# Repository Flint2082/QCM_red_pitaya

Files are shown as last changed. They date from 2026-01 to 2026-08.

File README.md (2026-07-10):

# QCM_red_pitaya

FPGA code for a quartz crystal microbalance measurement system. 
Designed to run on the Red Pitaya FPGA.
made using the CASPER toolflow.

The theory behind this system is described in detail in the accompanying thesis (in Dutch):
[Scriptie_V1.0_Flint_Wardenaar.pdf](docs/Scriptie_V1.0_Flint_Wardenaar.pdf).

## Setup
Red Pitaya setup instructions are available in the [Red Pitaya documentation](src/README.md).

## Controlling the system
Once the control software is running on the Red Pitaya, the instrument can be
driven from a script over its HTTP + WebSocket API. See
[tools/README.md](tools/README.md) for a Python control guide
([`qcm_client.py`](tools/qcm_client.py)).

## Block diagram



## Algorithm 
The system measures the frequency shifts of two modes of a quartz crystal microbalance (QCM) sensor: a temperature sensitive mode and a mass sensitive mode. The frequency shifts are modeled as polynomial functions of temperature change and mass change, represented by the following equations:
```math
    \begin{aligned}
        \Delta f_T &= \lambda_{T_3} \cdot \Delta T^3 + \lambda_{T_2} \cdot \Delta T^2 + \lambda_{T_1} \cdot \Delta T + \lambda_{T_0} \cdot \Delta m \\
        \Delta f_M &= \lambda_{M_3} \cdot \Delta T^3 + \lambda_{M_2} \cdot \Delta T^2 + \lambda_{M_1} \cdot \Delta T + \lambda_{M_0} \cdot \Delta m 
    \end{aligned}
```
Where:
-  $` \Delta f_T `$ : Frequency shift of the temperature sensitive mode
-  $` \Delta f_M `$ : Frequency shift of the mass sensitive mode
-  $` \Delta T `$ : Temperature change
-  $` \Delta m `$ : Mass change
-  $` \lambda_{T_i} `$ : Temperature coefficients for the temperature sensitive mode
-  $` \lambda_{M_i} `$ : Temperature coefficients for the mass sensitive mode

To isolate the temperature change $\Delta T$, we eliminate the mass change $\Delta m$ from the equations:
```math
    (\lambda_{M_3} \cdot \lambda_{T_0} - \lambda_{T_3} \cdot \lambda_{M_0}) \cdot \Delta T^3 +
    (\lambda_{M_2} \cdot \lambda_{T_0} - \lambda_{T_2} \cdot \lambda_{M_0}) \cdot \Delta T^2 + \\
    (\lambda_{M_1} \cdot \lambda_{T_0} - \lambda_{T_1} \cdot \lambda_{M_0}) \cdot \Delta T +
    \lambda_{M_0} \cdot \Delta f_T - \lambda_{T_0} \cdot \Delta f_M = 0
```
Then once $\Delta T$ is determined, we can substitute it back into one of the original equations to find the mass change $\Delta m$:
```math
    \Delta m = \frac{\Delta f_M - (\lambda_{M_3} \cdot \Delta T^3 + \lambda_{M_2} \cdot \Delta T^2 + \lambda_{M_1} \cdot \Delta T)}{\lambda_{M_0}}    
```

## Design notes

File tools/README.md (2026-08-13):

# Controlling the QCM from Python

The QCM control software on the Red Pitaya exposes an HTTP + WebSocket API (the
same one the web UI uses). [`qcm_client.py`](qcm_client.py) is a thin Python
wrapper around that API, so you can drive the instrument from a script instead
of the browser: lock the PLLs, start/stop a measurement, change settings,
manage crystal profiles, and stream live data.

- **REST (HTTP)** — every action and setting. One method per endpoint.
- **WebSocket** (`/ws`) — live push stream of measurements and state changes.

---

## 1. Prerequisites

The control software must already be running on the Red Pitaya. If you set it
up as a service it is always running; otherwise start it over SSH:

```bash
ssh root@<red_pitaya_ip>
cd /root/QCM_red_pitaya
.venv/bin/python src/main.py          # add --no-opcua if there is no PLC
```

See [src/README.md](../src/README.md) for full setup and the systemd service
(`systemctl status qcm`).

The server listens on **port 8000** on all interfaces, so from your PC it is
reachable at `http://<red_pitaya_ip>:8000`. Quick sanity check:

```bash
curl http://<red_pitaya_ip>:8000/health        # -> {"status":"ok"}
```

## 2. Install the client dependencies (on your PC)

The client needs `requests`; live streaming additionally needs
`websocket-client`:

```bash
pip install requests websocket-client
```

Both are listed at the bottom of [requirements.txt](../requirements.txt).

## 3. Connect

`qcm_client.py` has no package install step — just import it from the `tools/`
folder (run your script from there, or add `tools/` to `sys.path`).

```python
from qcm_client import QCMClient

qcm = QCMClient("192.168.1.50")     # host of the Red Pitaya; port defaults to 8000
print(qcm.state())                  # "IDLE", "LOCKING", "RUNNING", ...
```

Every method maps to one endpoint and returns the parsed JSON response (most
write calls return `{"status": "ok"}`). HTTP errors raise
`requests.HTTPError`.

---

## 4. Typical workflow

The normal sequence is **get lock → start measurement → read data → stop**.

```python
import time
from qcm_client import QCMClient

qcm = QCMClient("192.168.1.50")

# 1. Pick the crystal whose calibration you want to use (lock frequencies +
#    polynomial coefficients come from this profile).
qcm.activate_crystal("AT_cut_6MHz")

# 2. Lock the two PLLs onto the crystal's resonances.
qcm.get_lock()
time.sleep(2)                       # give the loops time to settle
print("state:", qcm.state())        # -> "RUNNING" once locked

# 3. Start a measurement run. ambient_temp is required; the others have
#    sensible defaults (gold density, Z-ratio 1.0).
qcm.start_measurement(ambient_temp=23.0, mat_dens=19320.0, z_ratio=0.381)

# 4. Stream live measurements over the WebSocket.
for m in qcm.stream_measurements(limit=20):
    print(f"{m.calculated_thickness:8.3f} nm   {m.calculated_temp:6.2f} °C")

# 5. Stop and pull the server-side CSV log of the whole run.
qcm.stop_measurement()
qcm.download_latest_run("run.csv")
```

A ready-to-run version of this is [`qcm_demo.py`](qcm_demo.py):

```bash
python qcm_demo.py 192.168.1.50         # run from the tools/ folder
```

### Oscillator index convention

Settings that take an `oscillator_idx` use:

| index | mode |
|---|---|
| `1` | mass-sensitive mode |
| `2` | temperature-sensitive mode|

### System states

`qcm.state()` (and the pushed `StateEvent`) returns one of:
`IDLE`, `LOCKING`, `RUNNING`, `SWEEPING`, `CAP_ADJUST`.

---

## 5. Live streaming over the WebSocket

`stream_measurements()` yields one object per measurement, with attribute
access to the fields of `MeasurementData`:

| attribute | meaning |
|---|---|
| `timestamp` | epoch seconds |
| `freq_mass_mode` | mass-mode frequency (Hz) |
| `freq_temp_mode` | temp-mode frequency (Hz) |
| `compensated_freq` | temperature-compensated mass frequency |
| `uncompensated_thickness`| raw Sauerbrey thickness (nm) |
| `calculated_thickness` | temperature-compensated thickness (nm) |
| `calculated_temp` | crystal temperature from the model (°C)  |
| `amp_mass`, `amp_temp` | demodulated amplitudes |
| `phase_mass`, `phase_temp`| demodulated phases |
| `lock_mass`, `lock_temp` | per-mode lock status (bool) |
| `quality_mass`, `quality_temp` | phase-error σ over the lock window (rad), lower is better; `None` until the window fills |

Everything above the compensated values is also published on its own as
`TelemetryEvent`, which the worker emits whenever a run is *not* in progress —
those fields need no measurement reference, so they stay live while idle. During
a run they ride along on `MeasurementEvent` instead, never both.

`stream()` is the general form — pass `types=None` to receive every event, or a
tuple to filter. Event `type` values you can receive:
`StateEvent`, `MeasurementEvent`, `TelemetryEvent`, `LockStatusEvent`, `LockFailedEvent`,
`SweepPointEvent`, `SweepCompleteEvent`, `CapAdjustEvent`, `TargetReachedEvent`,
`StartFreqAutoUpdatedEvent`, `ErrorEvent`, `OpcStatusEvent`.

```python
# Watch state changes and lock events instead of measurements:
for ev in qcm.stream(types=("StateEvent", "LockStatusEvent", "LockFailedEvent")):
    print(ev.type, vars(ev))
```

The stream is read-only (the server only pushes), and `limit=None` streams
forever — break out of the loop or set a `limit` to stop.

---

## 6. API reference

All methods are on `QCMClient`. Frequencies are in Hz unless noted.

### Measurement control
| method | endpoint | notes |
|---|---|---|
| `get_lock()` | `POST /measurement/get_lock` | lock both PLLs at the active crystal's frequencies |
| `start_measurement(ambient_temp, mat_dens=19320.0, z_ratio=1.0)` | `POST /measurement/start` | `ambient_temp` required; `mat_dens` kg/m³ |
| `stop_measurement()` | `POST /measurement/stop` | |
| `state()` | `GET /state` | returns the state string |
| `set_target_thickness(value)` | `POST /settings/target_thickness` | nm; 0 = no target |
| `target()` | `GET /measurement/target` | current target + whether it has been reached |

### Target thickness

Set a target and the system raises a flag the moment the compensated thickness
reaches it: a `TargetReachedEvent` on the WebSocket, a popup in the web UI,
`GVL_QCM.READ.TargetReached` on the PLC, and `reached: true` from
`GET /measurement/target`. **The measurement is not stopped** — the flag says
the film is thick enough, and stopping is left to whoever is watching (the
operator's STOP button, or the PLC acting on the node).

The flag clears when the next run starts, or if the target is raised above the
current thickness. `0` disables the target entirely.

```python
qcm.set_target_thickness(250)          # nm
qcm.start_measurement(ambient_temp=23)
for ev in qcm.stream(types=("TargetReachedEvent",), limit=1):
    print(f"reached {ev.thickness:.1f} nm of {ev.target:.1f} nm")
qcm.stop_measurement()
```

### Oscillator / lock settings
| method | endpoint |
|---|---|
| `set_frequency(oscillator_idx, frequency)` | `POST /settings/frequency` |
| `set_integrator_gain(oscillator_idx, gain)` | `POST /settings/integrator_gain` |
| `set_lpf_freq(oscillator_idx, freq)` | `POST /settings/lpf_freq` (demod low-pass cutoff) |
| `set_inverted(oscillator_idx, inverted)` | `POST /settings/inverted` |
| `set_output_mode(mode)` | `POST /settings/output_mode` (DAC debug tap, int 0–11) |
| `set_lock_detect(phase_tolerance, phase_std)` | `POST /settings/lock_detect` (both rad: max mean phase error, max phase-error σ) |
| `set_auto_relock(enabled)` | `POST /settings/auto_relock` (auto re-acquire on lost lock, default on) |
| `set_lock_frequencies(mass, temp)` | `POST /settings/lock_frequencies` (transient, feeds `get_lock`) |
| `get_lock_frequencies()` | `GET /settings/lock_frequencies` |
| `set_coefficients(fM_0..fM_3, fT_0..fT_3)` | `POST /settings/coefficients` (compensation polynomial) |
| `settings()` | `GET /settings` (everything at once) |

### Crystal profiles
A crystal profile stores its lock frequencies, compensation coefficients and
sensor parameters. Activating one applies all of them.

| method | endpoint |
|---|---|
| `crystals()` | `GET /crystals` → `{"crystals": [...], "active": name}` |
| `crystal(name)` | `GET /crystals/{name}` |
| `create_crystal(name)` | `POST /crystals` (seeds from current settings) |
| `apply_crystal(name, **fields)` | `POST /crystals/{name}/apply` (save explicit values + apply now) |
| `activate_crystal(name)` | `POST /crystals/{name}/activate` |
| `save_current_to_crystal(name)` | `POST /crystals/{name}/save_current` |
| `delete_crystal(name)` | `DELETE /crystals/{name}` |

### Frequency sweep (characterise resonances)
| method | endpoint |
|---|---|
| `start_sweep(oscillator_idx, start_freq, stop_freq, step_size, settle_time)` | `POST /sweep/start` |
| `sweep_mode(oscillator_idx, settle_time=0.05)` | 500 kHz window at 1 kHz around the crystal's lock frequency |
| `abort_sweep()` | `POST /sweep/abort` |
| `sweeps()` | `GET /sweeps` — sweep CSVs on the Pitaya, newest first |
| `download_sweep(name, dest_path)` / `download_latest_sweep(dest_path)` | `GET /sweeps/{name}/download` |
| `delete_sweep(name)` | `DELETE /sweeps/{name}` |

While sweeping, the server pushes `SweepPointEvent` (`frequency`, `amplitude`,
`phase`) then a final `SweepCompleteEvent` whose `name` is the CSV the sweep was
recorded to (`None` if recording failed).

Every sweep is written to `data/sweeps/` on the Pitaya as it is taken, so it
survives a dropped WebSocket. `sweep_mode()` is the scripted form of the
**SWEEP fM** / **SWEEP fT** buttons in the UI: it centres a 500 kHz window,
stepped at 1 kHz, on the active crystal's mass or temp lock frequency. That is
a coarse locator — wide enough to find a resonance that has moved well away
from the stored frequency, but too coarse to resolve the peak's shape. Narrow
the range and re-run once you know roughly where it sits.

```python
qcm.sweep_mode(1)                                  # sweep around fM
for _ in qcm.stream(types=("SweepCompleteEvent",), limit=1):
    pass                                           # wait for it to finish
qcm.download_latest_sweep("sweep.csv")
```

Plot the result with [`sweep_plotter.py`](sweep_plotter.py):

```bash
python sweep_plotter.py sweep.csv
```

It draws amplitude and phase against frequency and marks the two strongest
well-separated peaks — the same "peak / 2nd peak" the ANALYSIS tab reports. With
no argument it opens a file dialog or picks the newest `qcm_sweep_*.csv` from
the current directory, `./data/sweeps`, or your Downloads folder.

### Capacitor adjust (null the parasitic capacitance)
| method | endpoint |
|---|---|
| `start_cap_adjust()` | `POST /cap_adjust/start` |
| `stop_cap_adjust()` | `POST /cap_adjust/stop` |

Emits `CapAdjustEvent` (`amp_mass`, `amp_temp`) — minimise these.

### Server-side run logs
The worker writes a CSV for every measurement run on the Pitaya itself.
| method | notes |
|---|---|
| `runs()` | list saved runs, newest first |
| `download_run(name, dest_path)` | save a specific run locally |
| `download_latest_run(dest_path)` | save the most recent run locally |

### OPC-UA / PLC bridge
| method | endpoint |
|---|---|
| `opc_settings()` | `GET /opc/settings` |
| `opc_connect(url, user="", password="", base_node=None)` | `POST /opc/connect` |
| `opc_nodes()` | `GET /opc/nodes` (the node tree to mirror on the PLC) |

### System
| method | endpoint | notes |
|---|---|---|
| `reboot(force=False)` | `POST /system/reboot` | reboots the Pitaya; 409 during a run unless `force=True` |

A reboot reloads the FPGA bitstream and brings the PLLs up unlocked, so it is
the way out of a wedged instrument — but it ends any run in progress, keeping
only what the CSV had recorded up to that moment.

---

## 7. Without the Python client

The API is plain HTTP, so you can drive it from anything. Parameters are
**query-string** args, not JSON bodies:

```bash
curl -X POST "http://192.168.1.50:8000/measurement/get_lock"
curl -X POST "http://192.168.1.50:8000/measurement/start?ambient_temp=23&z_ratio=0.381"
curl       "http://192.168.1.50:8000/state"
curl -X POST "http://192.168.1.50:8000/measurement/stop"
```

---

## 8. Troubleshooting

- **`ConnectionError` / timeout** — the server isn't running or the host/port
  is wrong. Check `curl http://<host>:8000/health` and `systemctl status qcm`
  on the Pitaya.
- **`get_lock()` returns but state stays `LOCKING`, or you get a
  `LockFailedEvent`** — the start frequencies are off. Run a `start_sweep` to
  find the resonances, set them via the crystal profile, and retry.
- **State never reaches `RUNNING`** — you must `get_lock()` *before*
  `start_measurement()`.
- **`stream()` raises "Live streaming needs websocket-client"** — run
  `pip install websocket-client`.
- **`opc_connect` returns 503** — the server was started with `--no-opcua`.

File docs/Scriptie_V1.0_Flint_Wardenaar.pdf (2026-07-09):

# QCM Temperatuur Compensatie

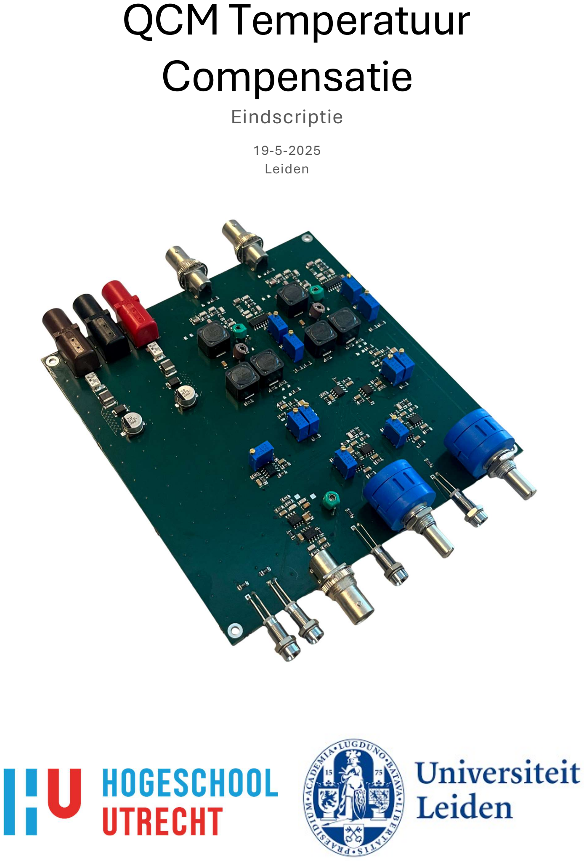
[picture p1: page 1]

## Eindscriptie

19-5-2025
Leiden

1

# QCM Temperatuur Compensatie

## Eindscriptie

19-5-2025
Leiden
Versie: | v1.0
Student: | Flint Wardenaar
Studentnummer: | 1771881
E-mail student: | Flint.wardenaar@student.hu.nl
Onderwijsinstelling: | Hogeschool Utrecht
Opleiding: | Electrical Engineering
Eerste examinator: | Hubert Schuit
Tweede examinator: | Michiel Scager
Afstudeerbedrijf: | Universiteit Leiden
Afdeling: | Elektronische Dienst
Bedrijfsbegeleider: | Harry Visser

Het bestuur van de Stichting Hogeschool Utrecht te Utrecht aanvaardt geen enkele aansprakelijkheid voor schade voortvloeiende uit het gebruik van enig gegeven, hulpmiddel, werkwijze of procedure in dit verslag beschreven. Vermenigvuldiging zonder toestemming van de auteur(s), de school of het bedrijf (indien van toepassing) is niet toegestaan.

2

## VOORWOORD

Voor u ligt de eindscriptie voor het QCM-temperatuurcompensatieproject, waarmee ik, Flint Wardenaar, dien af te studeren. Dit project wordt uitgevoerd in opdracht van en met ondersteuning van de Universiteit Leiden. Dit document heeft als doel de lezer een beeld te geven van het verloop van het project, de projectbeheersing, de gemaakte keuzes en de onderbouwing daarvan.
Ik ben erg dankbaar voor de kans om mijn afstudeeronderzoek uit te voeren bij de Universiteit Leiden, met een opdracht die mij bijzonder aanspreekt. Ik ben ervan overtuigd dat er geen betere afstudeerplek en geen geschiktere opdracht mogelijk waren.
Graag wil ik mijn begeleiders, Harry Visser en Raymond Koehler, bedanken voor hun steun en vertrouwen in mij. In het bijzonder wil ik Harry bedanken voor zijn eindeloze bereidheid om mee te denken en te sparren over mogelijke ontwerpoplossingen. Daarnaast ben ik mijn afstudeerbegeleider Michiel Scager zeer dankbaar, niet alleen voor zijn begeleiding tijdens mijn afstudeertraject, maar ook voor de afgelopen zes jaar waarin hij mij, vooral op het gebied van professionalisering, waardevolle lessen heeft geleerd. Zonder zijn begeleiding zou ik vandaag een heel ander persoon zijn.
Met veel enthousiasme presenteer ik dit document.
Flint Wardenaar
19-3-2025

3

## SAMENVATTING

Deze scriptie beschrijft het ontwikkeltraject van een quartz-crystal-microbalance (QCM) waarbij wordt gecompenseerd voor temperatuurveranderingen. Een QCM is een extreem gevoelige massasensor die veelal wordt ingezet in opdampopstellingen om de dikte van een neergeslagen materiaal laag te meten. Deze opdampopstellingen worden gebruikt voor het vervaardigen van onder andere supergeleiders, optische elementen en fotokathoden, waarbij het nauwkeurig bepalen van de laagdikte cruciaal is.
Een QCM werkt met een oscillerend kwarts kristal dat wordt blootgesteld aan de damp. Zodra materiaal zich op het kristal afzet, verandert de massa, wat resulteert in een verlaging van de resonante frequenties. Door deze frequentieverschuiving te meten, kan het verschil in massa en daarmee de laagdikte worden bepaald. Echter, tijdens het opdampen komt er veel warmte vrij waar het kristal door opwarmt. De warmte beïnvloedt de resonantiefrequentie van het kristal los van massatoename, wat leidt tot meetonnauwkeurigheden. Voor toepassingen waarbij de gewenste laagdikte minder dan één atoom bedraagt, is dit onacceptabel.
Om dit probleem aan te pakken is in dit project het V-model toegepast. Deze projectaanpak is gekozen vanwege de gestructureerde indeling in fasen en de nadruk op vroegtijdige validatie door testen — een belangrijke stap bij de ontwikkeling van meetsystemen.
Uit het literatuur- en praktijkonderzoek bleek dat temperatuurcompensatie mogelijk is door te kijken naar twee resonantiemodi van hetzelfde kristal. Doordat deze modi verschillend reageren op temperatuurveranderingen, kan het temperatuurverschil uit de meting worden geëlimineerd. Kristallen met een specifieke snijhoek, de zogenaamde SC-cut kristallen, zijn hiervoor bijzonder geschikt. Deze bevatten een extra resonantiemode met een sterke temperatuurafhankelijkheid, wat gunstig is voor het compenseren van temperatuureffecten. Het lukte om dit principe experimenteel te reproduceren, al was de meetnauwkeurigheid beperkt door de gebruikte meetmethode.
In eerste instantie werd gekozen voor een ontwerp met twee afzonderlijke oscillatoren die elk een resonantiemode van het kristal aansturen. Uit simulaties bleek echter dat deze aanpak instabiel en moeilijk af te stellen is. Daarom werd overgeschakeld op een ontwerp gebaseerd op een phase-locked loop (PLL), een analoog regelsysteem waarbij het uitgangssignaal een vast faseverschil heeft t.o.v. het ingangssignaal. In dit ontwerp stuurt het uitgangssignaal van de PLL het kristal aan. Wanneer het kristal in resonantie komt, introduceert dit een faseverschuiving. Door het faseverschil tussen het uitgangssignaal en het kristalsignaal constant te houden, blijft de uitgangsfrequentie gelijk aan de resonantiefrequentie. Deze frequentie kan vervolgens worden uitgelezen met een externe frequentieteller. Door twee van zulke systemen parallel te gebruiken op hetzelfde kristal, kunnen twee resonantiemodi simultaan worden gemeten.
Het ontwerp van het systeem is succesvol gerealiseerd, maar tijdens het testen is gebleken dat het nog niet in staat is om de resonantiefrequentie van het kristal correct te volgen. Er wordt echter verwacht dat deze functionaliteit alsnog kan worden bereikt na het doorvoeren van enkele technische aanpassingen. Om het onderliggende probleem te achterhalen, is een reeks gerichte vervolgtests opgesteld, waarbij het systeem modulair wordt geanalyseerd. Wanneer het systeem op technisch niveau naar behoren functioneert, kunnen de geplande functionele tests worden uitgevoerd. Tijdens deze tests zal worden onderzocht in hoeverre temperatuurveranderingen daadwerkelijk kunnen worden gecompenseerd, zoals beoogd in de doelstelling van het project.

4

## INHOUD

### 5.3 Hoe kan bij een dual-mode systeem de temperatuurgecompenseerde waarde

5.4 Hoe veel verschillen de eigenschappen tussen kristallen van dezelfde producent,

5

6

## INLEIDING

Binnen de Universiteit Leiden wordt veel onderzoek gedaan naar onder andere supergeleiders, halfgeleiders en Optical Near-Field Electron Microscopy (ONEM). Al deze technologieën maken gebruik van opdampen: een proces waarbij een extreem dunne laag materiaal wordt aangebracht op een substraat. Om de laagdikte tijdens dit proces nauwkeurig te monitoren, wordt gebruikgemaakt van een Quartz Crystal Microbalance (QCM). Deze sensor is in staat om minimale massaveranderingen te detecteren door verschuivingen in de resonantiefrequentie van een oscillerend kwarts kristal. Wanneer atomaire lagen op het kristal neerslaan, neemt de massa toe, waardoor de frequentie verandert — een verandering die direct kan worden omgezet naar een meting van de laagdikte.
Een belangrijk probleem bij het gebruik van een QCM is de temperatuurgevoeligheid. Tijdens het opdampen wordt het kristal blootgesteld aan intense warmtestraling van het verdampte materiaal, wat leidt tot het opwarmen van het kristal. Omdat de resonantiefrequenties van het kristal ook afhankelijk zijn van temperatuur, ontstaan er foutmetingen die niet te onderscheiden zijn van massa-effecten. Dit vormt een belemmering voor toepassingen waarbij sub-monolaag precisie vereist is.
Het doel van dit project is om een QCM-systeem te ontwikkelen dat temperatuurcompensatie toepast, zodat de invloed van opwarming op de meting wordt geminimaliseerd. Het beoogde prestatieniveau is een reductie van de temperatuurafhankelijkheid van 2 ppm/°C naar 0,2 ppm/°C, over een temperatuurbereik van 20 °C tot 100 °C. Om dit te realiseren is gebruikgemaakt van een methode waarbij twee resonantiemodi van het kristal tegelijk worden gemeten. Omdat elke mode verschillend reageert op temperatuurveranderingen, kan uit het verschil tussen beide een temperatuurcompensatie worden afgeleid.
Voor de uitvoering van dit project is gekozen voor het V-model als ontwikkelmethode. Deze aanpak biedt een gestructureerde werkwijze waarbij elke ontwerpfase direct wordt gekoppeld aan een bijbehorende testfase. Binnen dit project zijn de fasen doorlopen van eisenanalyse, functioneel ontwerp en technisch ontwerp. Momenteel bevindt het project zich in de fase van de technische tests.
De opbouw van dit document volgt de stappen van het V-model. In hoofdstuk 1 wordt de organisatie en werkwijze toegelicht. Hoofdstuk 2 behandelt het projectmanagement, waaronder de gekozen aanpak en evaluatie daarvan. In hoofdstuk 3 wordt de opdracht geschetst: de context, probleemstelling en eisen.
Hoofdstuk 4 vat het onderzoek uit het project-initiatie-document samen, gevolgd door het functioneel ontwerp in hoofdstuk 5 en het technisch ontwerp in hoofdstuk 6. Hierin worden alle subsystemen besproken en het uiteindelijke ontwerp gepresenteerd. In hoofdstuk 7 staan de testplannen en testresultaten. Het rapport sluit af met een conclusie.

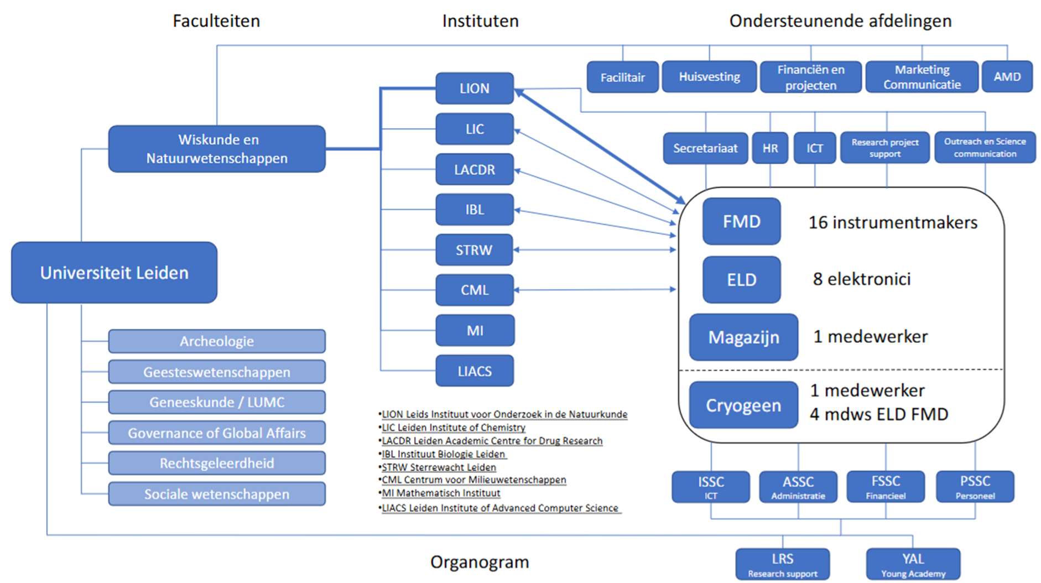
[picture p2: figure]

7

## 1 ORGANISATIE EN WERKWIJZE

### 1.1 ORGANISATIE

### 1.1.1 Universiteit Leiden – Faculty of Science

De Universiteit Leiden is een van de oudste en meest gerenommeerde universiteiten van Nederland. Binnen de Faculteit der Wiskunde en Natuurwetenschappen (Faculty of Science) worden verschillende wetenschappelijke disciplines beoefend, waaronder natuurkunde, scheikunde en biowetenschappen. Het Leids Instituut voor Onderzoek in de Natuurkunde (LION) is een van de belangrijkste instituten binnen deze faculteit en richt zich op fundamenteel en toegepast natuurkundig onderzoek.

### 1.1.2 Elektronische Dienst (ELD) en Fijn Mechanische Dienst (FMD)

Binnen de universiteit zijn de Elektronische Dienst (ELD) en de Fijn Mechanische Dienst (FMD) technische ondersteuningsafdelingen die op maat gemaakte oplossingen leveren voor wetenschappelijk onderzoek.
- De ELD richt zich op de ontwikkeling en realisatie van custom elektronica. Dit gebeurt uitsluitend wanneer commerciële oplossingen niet beschikbaar zijn, waardoor de ontwerpen vaak cutting-edge en sterk gespecialiseerd zijn.
- De FMD is verantwoordelijk voor de productie van op maat gemaakte mechanische componenten en precisie-instrumenten.
De ELD en FMD bestaan gezamenlijk uit ongeveer 24 medewerkers, waarvan 8 binnen de ELD en 17 binnen de FMD. Samen ondersteunen de ELD en FMD de onderzoeksprojecten van verschillende wetenschappelijke disciplines. Verreweg de meeste opdrachten komen vanuit het Leids Instituut voor Onderzoek in de Natuurkunde (LION). In Figuur 1-1 (Vergroot in bijlage
A) is de opbouw van de organisatie grafisch weergegeven.

Figuur 1-1: Organogram (klein) (Veldhuizen M., 2023)

8

### 1.2 WERKWIJZE

### 1.2.1 Partijen

Een aantal partijen spelen een rol in dit afstudeerproces. In deze lijst worden deze mensen benoemd.
Student:
Flint Wardenaar
Bedrijfsbegeleiders:
Harry Visser (hoofdbegeleider)
Raymond Koehler (tweede begeleider)
Academische begeleiding:
Michiel Scager (afstudeerbegeleider en tweede examinator) Hubert Schuit (eerste examinator)
Petra van Beek (afstudeercoördinator)

### 1.2.2 WERKUREN

De student werkt 40 uur per week, verdeeld over de vijf werkdagen. De student werkt vanuit huis op woensdagen. De student richt zich om van 9 tot 5 uur te werken. Deze tijden zijn echter redelijk flexibel. De student zou ook om 8 uur kunnen beginnen om zo eerder klaar te zijn.

### 1.2.3 Afspraken

Om het verloop van dit project te ondersteunen zijn de volgende afspraken gemaakt.

Voortgangsgesprek bedrijfsbegeleider
- Wie: Student, Bedrijfsbegeleider
- Wanneer: Elke donderdag 15:00
- Waar: Op kantoor
- Waarom: up-to-date houden bedrijfsbegeleider
- Wat: Een gesprek waarin de student een samenvatting geeft van zijn werkzaamheden van de afgelopen week en zijn plannen voor de aankomende week. Daarnaast is dit het moment voor het geven van feedback. Informeel is dit ook een moment om inhoudelijke zaken te bespreken.

Check-up gesprek Afstudeerbegeleider
- Wie: Student, Afstudeerbegeleider
- Wanneer: Elke week, dinsdag, 11:00
- Waar: Online, MS Teams
- Waarom: up-to-date houden afstudeerbegeleider
- Wat: Een gesprek waarin de student de leiding neemt om procesmatige en professionalisering gerelateerde zaken te bespreken. Vakinhoudelijke zaken zijn niet de prioriteit.

Leerteam meeting
- Wie: Student, Studentenleerteam
- Wanneer: Elke twee weken, Donderdag 14:00
- Waar: Online, MS-teams
- Waarom: mentale houvast bieden

9

- Wat: Een gesprek waarbij de studenten onderling zaken kunnen bespreken. Deze meeting is als informeel bedoeld en dient vooral als sociaal middel.

Status update mailtje
- Wie: Student, Afstudeerbegeleider
- Wanneer: Elke vrijdag
- Waar: Per e-mail
- Waarom: up-to-date houden afstudeerbegeleider en een logboek bijhouden
- Wat: De student maakt een beknopte samenvatting van zijn status. Hierbij gaat hij drie punten af: Inhoud, Proces en Persoonlijk.

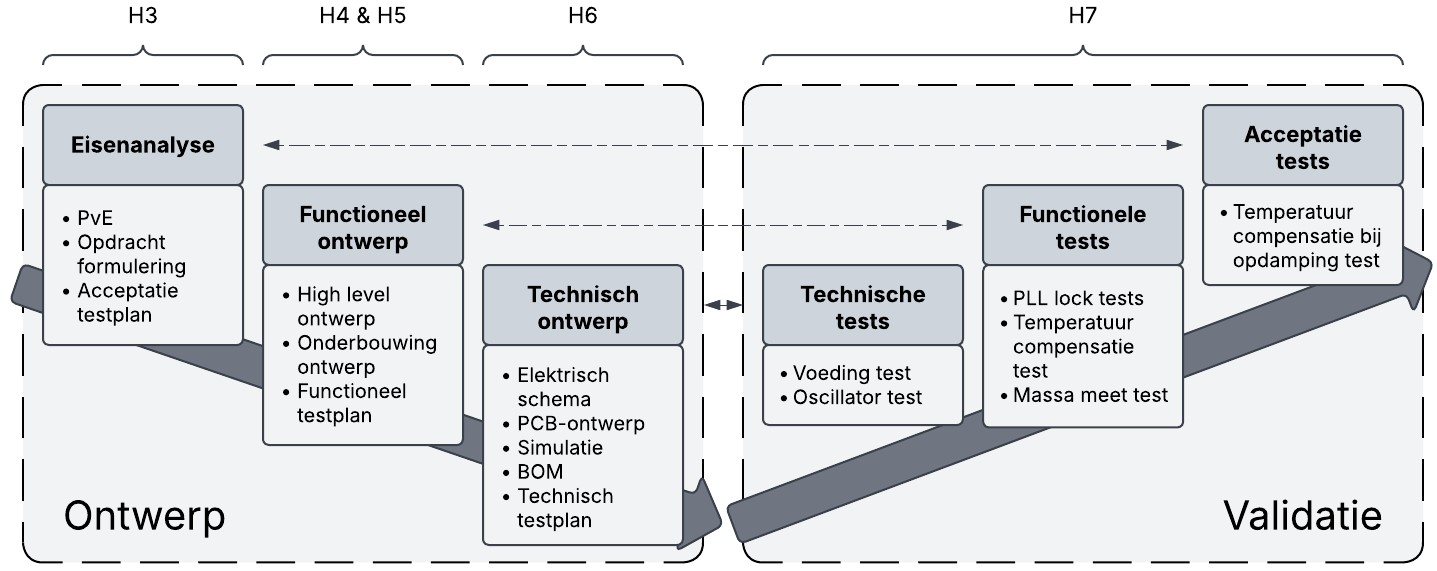
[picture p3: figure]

10

## 2 PROJECTMANAGEMENT

Dit hoofdstuk beschrijft hoe het ontwikkelproces van het systeem is gepland en aangestuurd. Er wordt uitgelegd welk ontwikkelmodel is gekozen en waarom, hoe deze methode is toegepast en hoe de planning is opgesteld en aangepast. Tot slot wordt de aanpak geëvalueerd.

### 2.1 V-MODEL

Voor dit project is gekozen voor het V-model als projectaanpak. Het V-model is een gestructureerde methode waarbij het ontwikkelproces wordt opgedeeld in twee hoofddelen: een aflopende reeks ontwerpfasen gevolgd door een oplopende reeks testfasen. Elke ontwerpstap aan de linkerzijde van de “V” correspondeert met een teststap aan de rechterzijde, gericht op validatie van het betreffende niveau (zie Figuur 2-1). Deze aanpak is voordelig in hardwareontwikkeling projecten, waarbij het vroegtijdig spotten van een fout veel tijd en geld kan schelen. Daarnaast is deze methode bijzonder geschikt voor de ontwikkeling van een meetinstrument, omdat het gestructureerd testen bijdraagt aan de betrouwbaarheid van het product.
Het project werd opgedeeld in fasen. Eerst werden in oplopende mate van detail de verschillende ontwerpniveaus doorlopen, van gebruikerswensen tot het concrete printplaatontwerp. Na afronding van elke ontwerpfase werd een bijbehorend testplan opgesteld dat zou worden uitgevoerd tijdens de corresponderende testfase.
In het project initiatie document zijn mijlpalen gekoppeld aan elke fase (Wardenaar F., 2025). Door deze mijlpalen al in het begin vast te leggen, kon een realistische planning worden opgesteld en werd het verloop van het project beter beheersbaar.

Figuur 2-1: V-model

### 2.2 TOELICHTING FASEN EN MIJLPALEN

Eisenanalyse [H3]:
De gebruikers wensen worden vertaald naar technische eisen
- PvE: Een eisenlijst waar de opdrachtgever mee in akkoord is gegaan
- Opdracht formulering: Een duidelijke formulering van de opdracht, goedgekeurd door de opdrachtgever

11

- Acceptatie testplan: Een testplan waarmee het systeem als geheel wordt getest a.d.h.v. de gestelde eisen

Functioneel ontwerp [H4 & H5]:
Door onderzoek uit te voeren wordt het systeem globaal ontworpen
- HLD: Een high level design, waarin het systeem tot op module niveau wordt beschreven
- Onderbouwing ontwerp: De belangrijke ontwerpkeuzes worden in een document benoemd en onderbouwd
- Functioneel testplan: Een testplan om losse functies van het ontwerp te testen

Technisch ontwerp [H6]:
De verschillende onderdelen worden volledig uitgewerkt
- Elektrisch schema: Een schema waarin het electrisch ontwerp in detail wordt beschreven
- Simulatie: Een simulatie van de te realiseren modules, om te bewijzen dat deze dienen te werken
- Pcb-ontwerp: Een digitaal ontwerp van een printplaat in een programma zoals KiCad
- BOM: Een lijst waarin alle gebruikte, en daarmee de te bestellen, componenten zijn aangegeven
- Technisch testplan: Een testplan om op module niveau te testen

Technische tests [H7]:
De gerealiseerde modules worden getest
- Voeding test: Een test waarin de voedingslijnen worden gemeten of ze de juiste spanning bieden en of er geen overmatige stromen lopen
- Oscillator test: Een test waarin de werking van de spanningsgestuurde oscillatoren worden beproefd.

Functionele tests [H7]:
Losse functionaliteiten van het systeem worden getest
- Temperatuurcompensatietest: Een test waarbij de temperatuur meet eigenschap van het systeem wordt beproefd
- Massameettest: Een test waarbij de massa wordt gemeten zonder temperatuur compensatie met de oorspronkelijke software

Acceptatie tests [H7]:
Het systeem wordt als geheel getest a.d.h.v. de gestelde eisen
- Temperatuur compensatie bij opdamping test: Een test die het systeem beproefd op het compenseren voor het opwarmen van het kristal in een realistisch opdamp scenario

### 2.2.1 Aanpassingen ten opzichte van PID

Gedurende het project zijn enkele aanpassingen doorgevoerd ten opzichte van het oorspronkelijke project initiatie document (Wardenaar F., 2025).

12

Softwareontwikkeling vervallen
De geplande softwareontwikkeling is geschrapt vanwege tijdsgebrek. Dit onderdeel was niet essentieel voor de opdracht, maar zou het testen vereenvoudigen en de demo verbeteren. Het werd beschouwd als een ‘nice to have’.

Realisatiefase vervallen
De realisatiefase is komen te vervallen, omdat het ontwerpen van de PCB en het samenstellen van de componentenlijst logischer binnen de technische ontwerpfase pasten. Het assembleren van de PCB – de enige activiteit die typisch in de realisatiefase valt – is uiteindelijk uitgevoerd door een collega, wegens tijdgebrek.

Aanpassingen in testfasen door gewijzigd ontwerp
Door het overschakelen van een dual-oscillator naar een PLL-ontwerp zijn de technische testplannen aangepast. Bovendien is de PLL lock test toegevoegd aan de functionele testfase.

### 2.3 STROKENPLANNING V2

Voor dit project is gebruikgemaakt van een strokenplanning om overzicht te houden van de tijdverdeling over de verschillende fasen en mijlpalen. In Figuur 2-2 is de planning te zien voor het inhoudelijke deel van het project. In Figuur 2-3 is de planning te zien waar de schoolproducten staan ingepland. Voor deze planning werd een online tool gebruikt (app.teamgantt.com). De planning werd initieel opgesteld aan de hand van de, in het PID geformuleerde, fasen en mijlpalen. Tijdens het project diende de strokenplanning als leidraad om voortgang te bewaken en tijdig bij te sturen wanneer vertragingen optraden, bijvoorbeeld door de keuze om van ontwerp te veranderen.

Figuur 2-2: Strokenplanning Inhoudelijk V2 (vergroot in bijlage C)

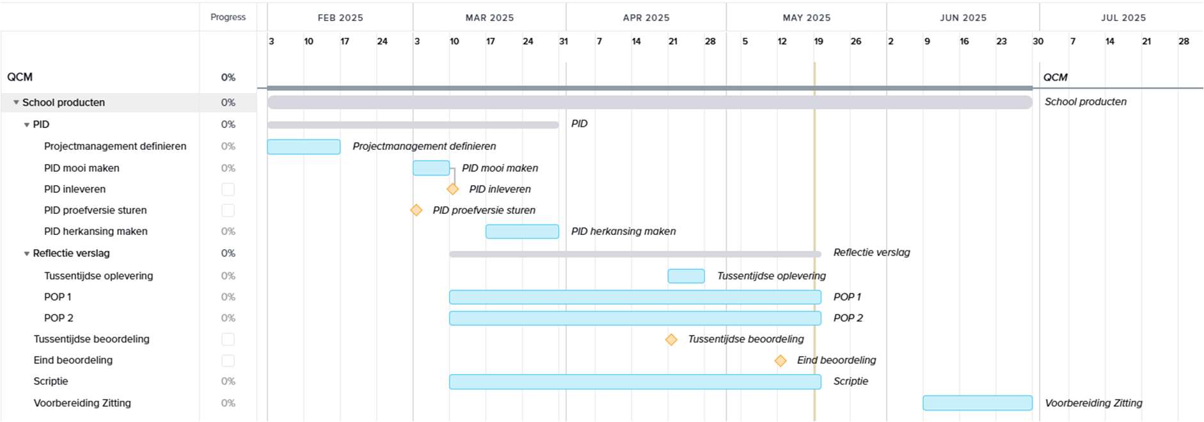
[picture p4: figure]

13

Figuur 2-3: Strokenplanning Schoolproducten V2 (vergroot in bijlage D)

### 2.3.1 Aanpassingen ten opzichte van V1

De planning is tijdens het project meerdere malen aangepast ten opzichte van de versie in het PID (zie bijlage B). De belangrijkste oorzaak was de vertraging door het wijzigen van de ontwerp richting en het moeten herkansen van het PID. Hierdoor verdwenen of veranderden sommige mijlpalen, en werd besloten het softwareonderdeel te laten vervallen.
Na ruim een maand gewerkt te hebben aan de initiële richting, moest teruggeschakeld worden naar de functionele ontwerpfase. Dit zorgde ervoor dat er aanzienlijk minder tijd overbleef voor het testen en valideren. Daardoor zou het project alleen volledig afgerond kunnen worden voor de deadline van het eindverslag (19 mei) als alle tests in één keer zouden slagen — wat niet realistisch is.
Daarnaast duurde het ontwerpen van de PCB een week langer dan gepland, wat extra ten koste ging van de testtijd.

### 2.4 EVALUATIE

Het V-model bleek een geschikte keuze voor dit project. De gefaseerde aanpak sloot goed aan bij de gestructureerde aard van hardwareontwikkeling. Vooral het vooraf definiëren van tests heeft bijgedragen aan overzichtelijke en doelgerichte validatiefasen. Tijdens het project werd de planning over het algemeen goed bijgehouden en bleef er voldoende overzicht over de voortgang. Het gestructureerd en fasegewijs werken volgens het V-model werkte prettig en gaf houvast.
Toch zijn er ook punten waarop verbetering mogelijk is. In de beginfase is er relatief weinig tijd besteed aan het uitdenken van mijlpalen. Hierdoor ontbrak het overzicht oorspronkelijk. Bij de herkansing van het PID is dit verbeterd door hier meer aandacht aan te besteden(Wardenaar F., 2025). Ook zijn er geen tijdsinschattingen gemaakt per mijlpaal, wat het achteraf lastig maakte om te reflecteren op de planning ten opzichte van de daadwerkelijke tijdsbesteding. In een volgend project zou dit beter meegenomen kunnen worden. Daarnaast zou het plannen van een kleine buffer bij elke mijlpaal verstandig zijn, om eventuele vertraging op te vangen zonder direct in de knel te komen met de rest van de planning.

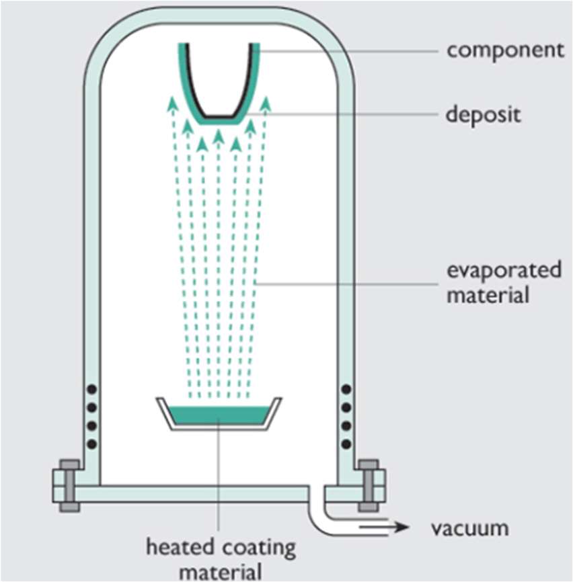
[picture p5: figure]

14

## 3 OPDRACHT

Dit hoofdstuk beschrijft de fase “eisenanalyse” (zie H2) en is grotendeel overgenomen uit het project initiatie document (Wardenaar F., 2025). De mijlpalen van deze fase, het PvE, de opdrachtformulering en het acceptatie testplan zijn allen behaald.

### 3.1 CONTEXT

Om de opdracht te kunnen begrijpen is het van belang om de context te weten. Hier zal de context worden geschetst.

### 3.1.1 Opdampen/sputteren

De opdrachtgever is een wetenschapper bij het LION die in bezit is van meerdere opdamp- en sputteropstellingen (ongeveer vijf in totaal). Opdampen is een techniek waarbij een materiaal in een hoog vacuüm wordt verhit, bijvoorbeeld met een gloeidraad of een elektronenstraal. Dit proces wordt ook wel “Physical vapor deposition” of PVD genoemd. Zodra het materiaal een voldoende hoge temperatuur bereikt, verdampt het en condenseert het op oppervlakken binnen de vacuümkamer. Hiermee kunnen dunne lagen materiaal met grote precisie worden aangebracht.

Figuur 3-1: Diagram van een standaard PVD-opstelling(Bellardita et al., 2019)
Sputteren is een alternatieve methode om een vergelijkbaar resultaat te bereiken, maar maakt gebruik van geïoniseerd gas als energiebron. Door botsingen tussen de ionen en het doelmateriaal worden atomen losgeslagen, die zich vervolgens afzetten als een dunne laag op een substraat. Beide technieken worden veel toegepast in onderzoek en industrie om materialen met gecontroleerde eigenschappen te creëren.

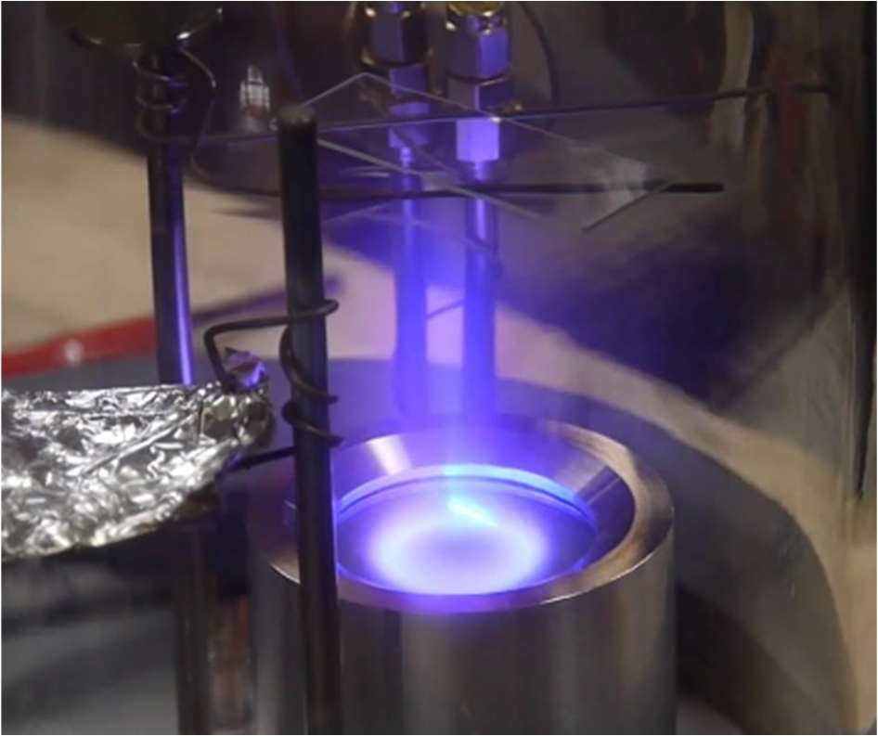
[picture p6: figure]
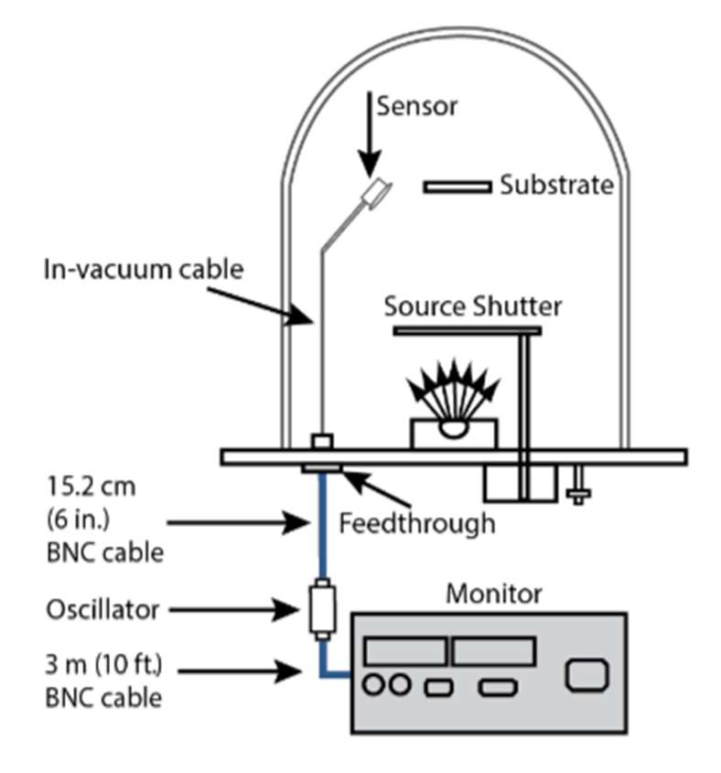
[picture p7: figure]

15

Figuur 3-2: Sputter-opstelling waarin een microscoop-slide wordt gecoat met koper (Krasnow B., 2013)

### 3.1.2 QCM

Om de dikte van de opgedampte laag nauwkeurig te monitoren, wordt een Quartz Crystal Microbalance (QCM) gebruikt. Dit is een oscillerend kwartskristal dat in contact staat met de damp in de vacuümkamer. Wanneer materiaal op het kristal neerslaat, neemt de massa van het kristal toe, wat resulteert in een meetbare verlaging van de resonantiefrequentie.
Het diagram in Figuur 3-3 (INFICON, 2021) laat zien hoe een typisch QCM-systeem er uit ziet. Het systeem is op te delen in drie modules: De sensor, de oscillator en de frequentieteller.

Figuur 3-3: Diagram commercieel QCM-systeem (INFICON, 2021)
De relatie tussen de massa- en de frequentieverandering wordt beschreven door de Sauerbrey-vergelijking (Sauerbrey, 1959):

Δm =

−C
n
⋅ Δf | [3. a]

Waarbij Δm de massaverandering is, C een constante is die afhankelijk is van de kristaleigenschappen en temperatuur,n de gebruikte harmonische mode van het kristal is en Δf de frequentieverandering is.

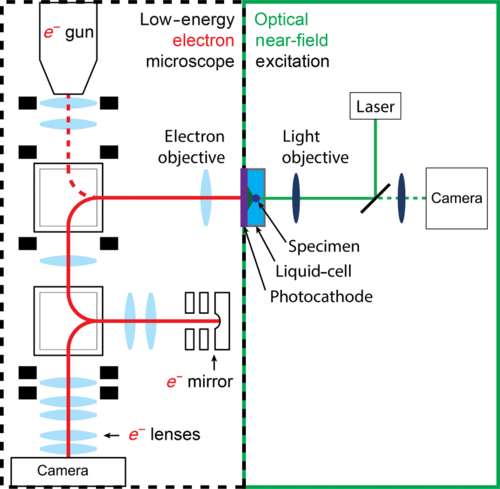
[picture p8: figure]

16

Hieruit blijkt een lineair verband tussen de massa-afname en de frequentieverandering. Dit maakt QCM een essentieel instrument voor het nauwkeurig controleren van opdamp- en sputterprocessen.

### 3.1.3 ONEM

De opdrachtgever verricht onderzoek naar Optical-nearfield-electron-microscopy (ONEM). Dit is een nieuwe microscopietechniek die een veel hogere vergroting biedt dan een optische microscoop, zonder schade toe te brengen aan gevoelige biologische samples(Marchand et al., 2021). De resolutie van een klassieke optische microscoop wordt beperkt door de relatief grote golflengte van licht, waardoor details kleiner dan 0,2 µm niet zichtbaar zijn. Deze beperking, bekend als de diffractielimiet (Alvelid et al., 2019) geldt echter alleen wanneer een object van een afstand groter dan één golflengte wordt waargenomen.
ONEM maakt gebruik van dit principe door het licht kort na interactie met de sample om te zetten in een elektronenbundel. Dit wordt bereikt door een fotokathode op de monsterhouder aan te brengen. Deze laag bevat zwak gebonden elektronen die, wanneer ze door licht worden geraakt, vrijkomen. De gegenereerde elektronen worden vervolgens gedetecteerd met een low-energy-electron-microscope (LEEM) (Figuur 3-4).

Figuur 3-4: Functioneel schema ONEM (Marchand et al., 2021)

### 3.2 PROBLEEMSTELLING

Bij ONEM speelt het opdampen van materialen een cruciale rol. De fotokathode bestaat uit een extreem dunne laag cesium, zo’n 5nm of 187 atomen dik, waardoor minimale variaties in de laagdikte al grote invloed kunnen hebben op de prestaties. Momenteel wordt slechts een fractie van de verwachte vrije elektronen waargenomen in vergelijking met theoretische modellen. Een van de mogelijke oorzaken van deze afwijking is een onnauwkeurigheid bij het opdampen van de fotokathode.
Deze onnauwkeurigheid stamt uit het feit dat het sensor kristal opwarmt tijdens het opdampproces. Door deze opwarming verhoogt de eigenfrequentie van het kristal. Dit effect zorgt voor een fout in de gemeten opdampdikte. Deze fout is bij alle opdampopstellingen

17

aanwezig, maar omdat de toleranties daar zo klein zijn, vormt dit een limitatie in het onderzoek naar ONEM.

### 3.3 OPDRACHTFORMULERING

De opdracht luidt als volgt:
“Ontwikkel en test een Quartz-Crystal-Microbalance PoC, voor het nauwkeurig meten van opgedampte laagdikten, waarbij gecompenseerd wordt voor het opwarmen van de sensor”

### 3.4 PVE –MOSCOW

In overleg met de opdrachtgever is de volgende eisenlijst tot stand gekomen.

Tabel 3-1: PvE - MoSCoW
Nr. | Eis | Toelichting
| 1 | | Must haves | Essentieel voor een succesvol
project

### 1.1 De gemeten waarden zijn met minder dan

0.2ppm/°C afhankelijk van de temperatuur van
het kristal

Het ongecompenseerde kristal heeft een afhankelijkheid van ongeveer 2ppm/°C tussen 20 en 100 c (uit eigen metingen in Error! Reference source not found.). Een tienvoud verbetering wordt ingeschat als een haalbaar en wenselijk doel.
1.2 De gestelde eisen worden behaald bij kristal | | Bij een zware thermische belasting
| temperatuur van 20 t/m 100 °C | van het kristal is de temperatuur
niet hoger dan 90°C geworden (zie Error! Reference source not found.). Deze waarde is omhoog afgerond.
2 | Should haves | Gewenst, maar niet strikt
| | noodzakelijk
2.1 Het systeem heeft een meetinterval van | | De opdampregelaar heeft snelle
| maximaal 100ms | feedback nodig

### 2.2 Het systeem behaalt een meetresolutie van

0.01nm

De gewenste opdampsnelheid is 0.10nm/s. door de 100ms
meetinterval zal de resolutie een tiende hiervan moeten zijn.
2.3 Het kristal en de aangesloten kabels zijn geschikt | | Ze mogen geen gassen uitzetten
| voor UHV | die het vacuüm degradeert

### 2.4 Het systeem stuurt zijn metingen door naar een

PC

De computer die de
opdampsnelheid regelt gebruikt deze data als feedback
2.5 De enige elektrische toegang tot het vacuüm is | | De huidige opstelling gebruikt deze
| via één BNC-connector | connector

### 2.6 Het maximale frequentieverloop als gevolg van

opgedampte massa, voordat het kristal
vervangen dient te worden is 5%

De kristallen hebben een bepaalde levensduur voordat ze vervangen dienen te worden. Bij een dikke laag opgedampt materiaal zal dit mechanische invloed hebben op

18

het kristal. Onder de 5% is de verhouding tussen laagdikte en frequentie nagenoeg lineair (Wajid, 1997)
3 | Could haves | Optioneel, Alleen als hier tijd
| | voor is

### 3.1 Het kristal past in de substraathouder van de

| LEEM met een binnendiameter van 8mm | De momenteel gebruikte kristallen
| | zijn te groot hiervoor met een
| | diameter van 12mm
3.2 Er zit 40cm unshielded kabel tussen de oscillator | | De kabels naar de
| en het kristal | substraathouder binnen in de
LEEM zijn niet shielded
4 | Wont haves | Buiten scope van dit project
4.1 | De frequentieteller wordt zelf ontwikkeld | Deze zijn off-the-shelf beschikbaar
4.2 | Het kristal wordt zelf ontwikkeld | Deze zijn off-the-shelf beschikbaar
4.3 Het systeem compenseert voor de mechanische | | Mechanische eigenschappen
| eigenschappen van het opgedampte materiaal | worden pas significant nadat er
| (Z-factor) | grote hoeveelheden zijn
opgedampt(Wajid, 1997)

### 3.5 PRODUCTEN

Tijdens het afstudeertraject worden verschillende producten opgeleverd die zowel het ontwikkelproces als het eindresultaat documenteren en ondersteunen. Deze producten zijn onderverdeeld in drie categorieën:

### 1. Documentatie

De documentatie omvat een technisch verslag van het project. Dit is een gecondenseerde versie van de eindscriptie met als doel om het project overdraagbaar te maken.

### 2. Proof of Concept (PoC)

Het centrale resultaat van dit project is een werkend prototype: een hardwarematig gerealiseerd QCM-systeem met temperatuurcompensatie. De focus ligt tijdens het afstuderen op het opleveren van de hardware. De bijbehorende software, waarmee bijvoorbeeld de kalibratie en uitlezing geautomatiseerd kunnen worden, zal na inlevering van de scriptie verder worden ontwikkeld.

### 3. Schoolproducten

In het kader van de opleiding worden daarnaast een aantal verplichte documenten opgeleverd. Dit betreft het Project Initiatie Document (PID), waarin het projectvoorstel en de aanpak zijn vastgelegd, de scriptie zelf als hoofdrapportage van het afstudeerwerk, een verslag van het professioneel functioneren, twee feedback formulieren en een eindpresentatie. De presentatie wordt verzorgd na het inleveren van de scriptie.
Deze producten vormen gezamenlijk het bewijs van de ontwikkeling, uitvoering en reflectie binnen het afstudeerproject.

19

## 4 SAMENVATTING ONDERZOEK PID

Dit hoofdstuk vat het onderzoek uit het PID samen. Meer detail is te vinden in Hoofdstuk 3 van het PID (Wardenaar F., 2025). Dit hoofdstuk vormt het eerste deel van de fase functioneel ontwerp.
De vijf deelvragen gaan over de werking van bestaande QCM-systemen, de oorzaken en gevolgen van opwarming van het kristal, hoe warm het kristal wordt, en hoe hiervoor gecompenseerd kan worden.

### 4.1 HOE WERKEN BESTAANDE QCM-SYSTEMEN

QCM-systemen bestaan uit drie hoofddelen: het kristal (sensor), een oscillator en een frequentieteller (Figuur 4-1).

Figuur 4-1: Typische QCM-opstelling (Nanoscience, n.d.)

### 4.1.1 Kwarts kristal

Dankzij het piezo-elektrisch effect kan een kwarts kristal zowel vervormen door elektrische spanning als zelf spanning opwekken bij vervorming. Voor QCM-toepassingen worden dunne schijfvormige kristallen met een diameter van ca. 12 mm gebruikt, met een basisfrequentie van 5 of 6 MHz. Deze kristallen hebben een hoge Q-factor, wat zorgt voor een stabiele frequentie. De oscillatiefrequentie van het kristal is lineair gerelateerd aan zijn massa, waardoor massa- en laagdiktemetingen mogelijk worden. Een belangrijke parameter is de snede van het kristal (zoals AT-cut of SC-cut), die invloed heeft op temperatuurgevoeligheid en mechanische stabiliteit. SC-cut kristallen kunnen naast de fundamentele C-mode en spurious-modes, ook in B-mode oscilleren.
De B-mode ligt doorgaans ~10% boven de eerste harmonische en is vooral van belang in toepassingen waar temperatuurcompensatie gewenst is. Praktijkmetingen met een netwerkanalyser bevestigen het bestaan van deze modi (Figuur 4-2 ). Tot slot wordt het fysieke ontwerp van het kristal en zijn houder besproken, inclusief de elektrodestructuur en de toepassing van waterkoeling om temperatuurinvloeden te minimaliseren.

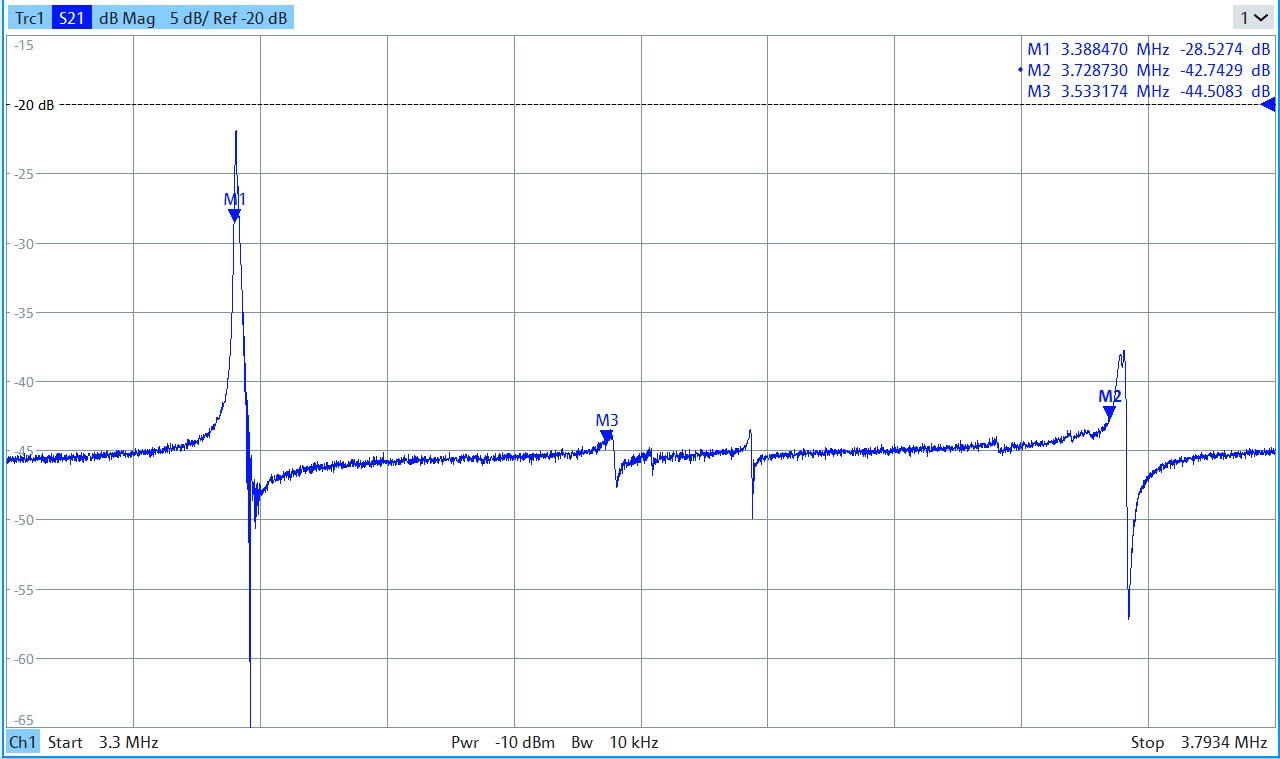
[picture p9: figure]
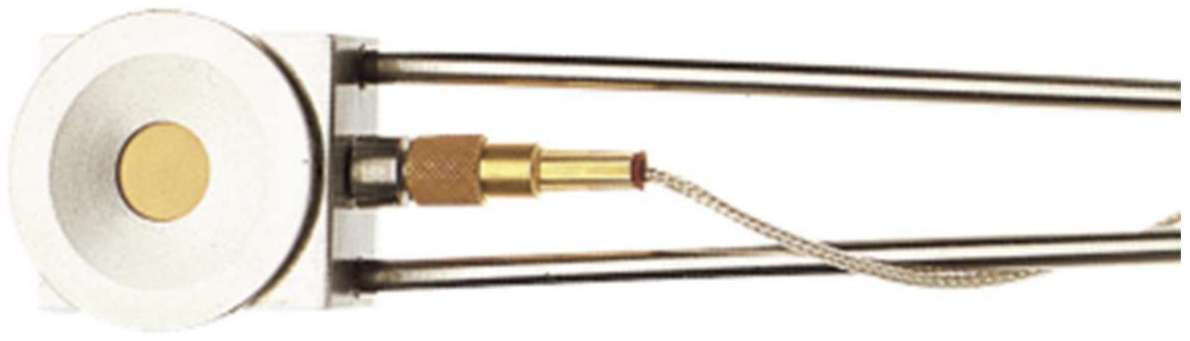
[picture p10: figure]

20

Figuur 4-2: Schermafbeelding van de netwerk analyser aangesloten op een 3.3MHz SC-cut kristal (M1: C-mode, M2: B-mode, M3: Spurious mode)
Het kristal is voorzien van twee elektroden en wordt in een houder geplaatst die het kristal aan de randen klemt (zie Figuur 4-3). Eén elektrode maakt contact met de geaarde houder, terwijl de andere via een veercontact verbonden is met een kabel die naar de oscillator leidt. De houder van het kristal is voorzien van waterkoeling.

Figuur 4-3: Commerciële QCM sensor met waterkoeling - De gouden cirkel is het kristal (Front Load Single Sensor, n.d.)

### 4.1.2 Oscillator

De oscillator drijft het kristal aan door het gegenereerde signaal te versterken en terug te koppelen. Door filters toe te passen kan men specifieke oscillatiemodi selecteren. Een banddoorlaatfilter op de gewenste frequentie zorgt ervoor dat alleen deze mode wordt versterkt, terwijl andere onderdrukt worden. Door te filteren op een hogere harmonische kan men hogere frequenties behalen.

### 4.1.3 Frequentieteller

Een frequentieteller meet de frequentie van het oscillatiesignaal met hoge nauwkeurigheid. Binnen de huidige opstellingen binnen de Universiteit Leiden wordt hiervoor een Keysight 53220A gebruikt, die frequenties meet tot op 11 decimalen nauwkeurig, met een meetinterval van 100 ms. De gemeten waarden worden vervolgens doorgestuurd naar een computer voor verdere verwerking.

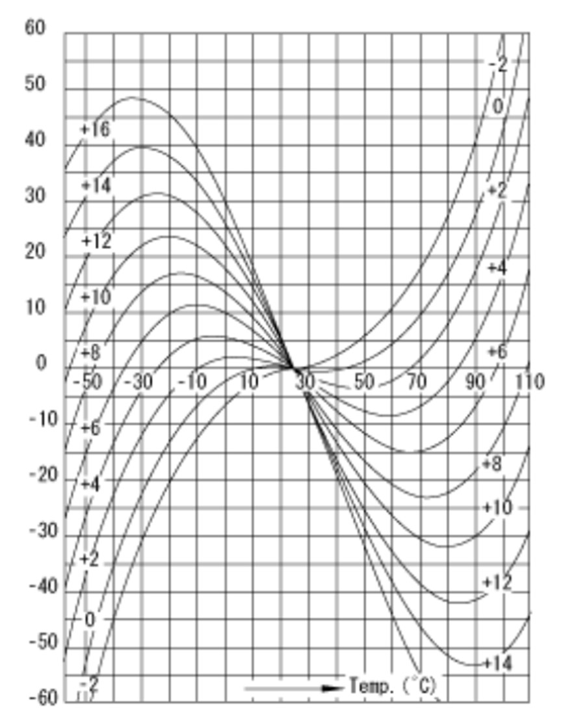
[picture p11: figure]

21

### 4.2 WAARDOOR WARMT HET KRISTAL OP?

In een vacuüm is warmteafvoer lastig. Van drie mogelijke warmtebronnen (opgedampt materiaal, mechanische wrijving, en warmtestraling) blijkt stralingswarmte van het hete bronmateriaal de enige significante oorzaak van opwarming. De andere bronnen zijn verwaarloosbaar.

### 4.3 WAT IS HET EFFECT VAN WARMTE OP HET KRISTAL?

Uit literatuur blijkt dat de relatie tussen temperatuur en resonante frequentie van een kwarts kristal typisch een S-curve volgt, oftewel een derdegraads polynoom. Voor AT-cut kristallen is het temperatuurstabiele punt rond kamertemperatuur gekozen, terwijl dit bij SC-cut kristallen rond de 80°C ligt. De precieze temperatuurrespons blijkt sterk afhankelijk van de snijhoek van het kristal, wat zichtbaar is in Figuur 4-4. Deze karakteristiek is experimenteel gevalideerd.

Figuur 4-4: Temperatuur respons AT-cut kristal, uit literatuur (y = frequentieverandering in ppm, x = temperatuur in graden C, de verschillende curves geven verschillende snijhoeken aan in hoekminuten)

### 4.4 HOE WARM WORDT HET KRISTAL?

Een experiment met opdampen van niobium toonde aan dat het kristal maximaal tot ongeveer 90°C opwarmde. Dit werd indirect afgeleid uit de frequentieverschuiving na het opdampen. Hoewel de meting onnauwkeurig was, geeft het een indicatie van het maximale temperatuurbereik.

### 4.5 HOE KAN TEMPERATUUR HET BEST GECOMPENSEERD WORDEN?

Voor temperatuurcompensatie in een QCM-systeem zijn drie benaderingen overwogen. De eerste methode betrof het gebruik van een infraroodsensor (IR-sensor) die achter het kristal wordt geplaatst om de temperatuur non-contact te meten. Hoewel dit conceptueel aantrekkelijk is, bleek het technisch uitdagend in de praktijk, vooral vanwege de moeilijkheid om een betrouwbare meting uit te voeren in een vacuümomgeving.

22

Een tweede methode maakte gebruik van een thermokoppel dat werd geplaatst op een dummy-kristal naast het actieve kristal. Deze opstelling had als voordeel dat het temperatuurgedrag van een fysiek vergelijkbaar kristal werd gemeten zonder het daadwerkelijke meetsignaal te beïnvloeden. Echter, deze methode introduceert onnauwkeurigheden: de toevoeging van een thermokoppel aan het kristal wat zelf maar een paar milligram weegt, zal de thermische eigenschappen significant beinvloeden. Daarbij komt ook nog kijken dat de gemeten temperatuur altijd achter zal lopen op de daadwerkelijke kristaltemperatuur.
De derde en meest veelbelovende methode is dual-mode compensatie. Hierbij wordt het kristal zelf gebruikt als temperatuursensor door twee verschillende oscillatiemodi tegelijk te meten (Song et al., 2024). Doordat deze modi elk een andere gevoeligheid hebben voor temperatuurveranderingen, kan de massametingen hiervoor worden gecorrigeerd.
Deze dual-mode methode vereist geen extra sensoren of bedrading binnen de vacuümkamer, en kan daarom makkelijk worden toegepast op bestaande systemen. Het compensatieprincipe is experimenteel gevalideerd binnen dit project. Op basis van deze bevindingen is besloten deze aanpak te implementeren in het uiteindelijke ontwerp.

23

## 5 FUNCTIONEEL ONTWERP

Dit hoofdstuk behandelt het tweede deel van de functioneel ontwerpfase. In deze fase zijn belangrijke mijlpalen gerealiseerd, waaronder het high-level ontwerp, de onderbouwing van ontwerpkeuzes en het opstellen van het functioneel testplan. Het high-level ontwerp en het voorafgaande onderzoek worden in dit hoofdstuk toegelicht; het testplan is te vinden in paragraaf 7.1.2.

### 5.1 WAT IS DE GEWENSTE FREQUENTIEMEETRESOLUTIE?

In punt 2.2 van het PvE staat dat het systeem een laagdikte van 0.01nm moet kunnen onderscheiden. De Sauerbrey-vergelijking 4.a (Sauerbrey, 1959) geeft de verhouding tussen de frequentieverandering van de resonante mode ten gevolge van een verandering in massa.

Δf =

2f
Aρμ
⋅ Δm | [4. a]

Hierbij is Δf de verandering van de frequentie, Δm de verandering van de massan, f de startfrequentie, A is het oppervlakte, ρ de dichtheid en μ de shear-modulus van het kwarts kristal.
Vergelijking 4.b geeft de verhouding tussen verschil in massa en laagdikte d. Waarbij ρ de dichtheid van de opgedampte massa representeert
Δm = Δd ⋅ Aρ | [4. b]
Vergelijking 4.c combineert de vorige vergelijkingen. Opmerkelijk is dat het oppervlakte van het kristal niet meer een factor is.

Δf =

Δd ⋅ 2fρ ρμ | [4. c]

Uit deze vergelijking is te constateren dat bij het opdampen van 0.01nm aluminium, gekozen als worst case, de fundamentele mode van 3.3MHz met 1.3Hz zal verlagen.
Om te voldoen aan de should-have die stelt dat er 0.01nm meetresolutie behaalt dient te worden, is een frequentiemeetresolutie van afgerond 1Hz vereist.

### 5.2 WELKE MODI ZIJN HET BESTE GESCHIKT VOOR TEMPERATUUR COMPENSATIE?

Kwarts kristallen hebben verschillende resonante modi. Deze modi hebben allen een unieke temperatuur-frequentie (T-f) karakteristiek. Er is onderzocht welke twee modi het meest geschikt zijn om voor de temperatuur te compenseren.

Beoordelingscriteria
Bij het selecteren van geschikte modi voor temperatuurcompensatie zijn twee eigenschappen van belang, afhankelijk van de toepassing. Voor het behalen van de hoogste nauwkeurigheid moeten de twee modi de volgende eigenschappen hebben: De zogenaamde mass-mode vereist een zo laag mogelijke temperatuurafhankelijkheid en is dus voornamelijk beïnvloed door de opgedampte massa, terwijl de temperature-mode juist een hoge temperatuurafhankelijkheid vereist.

24

Daarnaast is het belangrijk dat het verschil in temperatuurrespons tussen de gekozen modi een monotone karakteristiek vertoont binnen het temperatuurbereik van 20 °C tot 100 °C. Dat wil zeggen dat de karakteristieke lijn altijd stijgt of daalt. Een monotone relatie voorkomt ambiguïteit bij het afleiden van temperatuur uit frequentieverschillen, omdat elke frequentieverandering overeenkomt met slechts één temperatuurverandering.

Beschikbare modi
Voor het ontwerp zijn verschillende resonantiemodi van het SC-cut kristal onderzocht. De volgende modi kwamen hierbij naar voren:
- C-mode 1e orde (~6 MHz)
- C-mode 3e orde (~18 MHz)
- B-mode 1e orde (~6,7 MHz)
- B-mode 3e orde (~20 MHz)
- Spurious/anharmonische modi (~6,3 MHz)

Onderzoeksmethode
Voor het karakteriseren van de modi is het kristal aangesloten op een network-analyzer (NA). Door een sweep uit te voeren over een frequentiegebied, worden de resonantiemodi zichtbaar als versterkingspieken.
Het kristal wordt vervolgens stapsgewijs verwarmd met behulp van een hot-plate. Een thermokoppel is bevestigd aan de behuizing van het kristal om de temperatuur te meten. Bij elke temperatuurstap wordt de resonantiefrequentie van elke zichtbare mode vastgelegd. Hierbij wordt genoeg tijd geboden voor het kristal om op temperatuur te komen.
Op basis van deze metingen worden T-f karakteristieken opgesteld voor elke mode.

Resultaten
De gemeten temperatuurcoëfficiënten en karakteristieken zijn als volgt:
- C-mode 1e orde (~6 MHz):
Temperatuurcoëfficiënt: –6,5 Hz/K
Gedrag: monotoon dalend
- C-mode 3e orde (~18 MHz): Temperatuurcoëfficiënt: +2,7 Hz/K Gedrag: niet-monotoon
- B-mode 1e orde (~6,7 MHz): Temperatuurcoëfficiënt: –84 Hz/K
Gedrag: monotoon dalend
- B-mode 3e orde (~20 MHz):
Resonantie: te zwak voor betrouwbare meting met de NA
- Spurious/anharmonische modi (~6,3 MHz):
Resonantie: te zwak voor betrouwbare meting met de NA

Conclusie
Op basis van de gemeten karakteristieken is de volgende combinatie het meest geschikt voor temperatuurcompensatie:

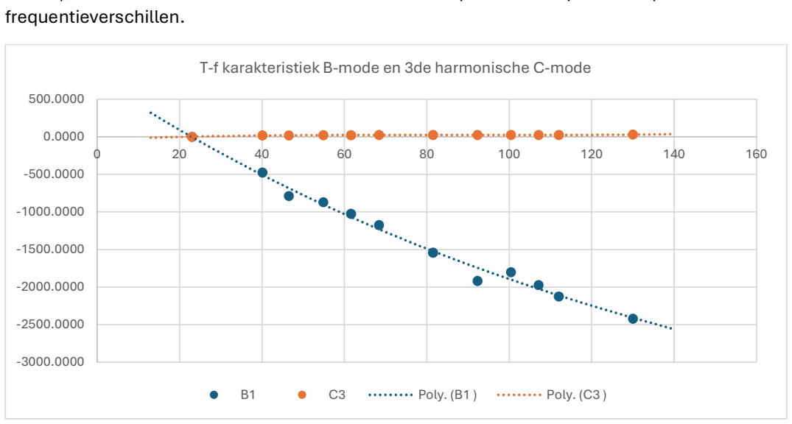
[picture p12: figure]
frequentieverschillen.; Poly. (B1 ); Poly. (C3 )

25

- Voor de mass-mode is C-mode 3e orde het meest vanwege de lage absolute drift.
- Voor de temperature-mode is B-mode 1e orde het meest geschikt, dankzij de sterke en monotone temperatuurafhankelijkheid.
Figuur 5-1 toont de karakteristieken van deze modi. Het verschil in frequentie tussen deze twee modi vertoont een monotone T-f karakteristiek over het relevante temperatuurbereik (20 °C – 100 °C), wat deze combinatie bruikbaar maakt voor temperatuurcompensatie op basis van

Figuur 5-1: Test resultaten T-f karakteristiek B1-mode en C3-mode (x = temperatuur [°C], y = afwijking frequentie [ppm])

### 5.3 HOE KAN BIJ EEN DUAL-MODE SYSTEEM DE TEMPERATUURGECOMPENSEERDE

WAARDE BEREKEND WORDEN?
In een dual-mode QCM-systeem worden twee resonantiemodi van hetzelfde kristal gelijktijdig gebruikt: de mass-mode en de temperature-mode. Door beide frequentieverschuivingen met elkaar te combineren, is het mogelijk om het temperatuureffect weg te filteren en enkel de massa-gerelateerde frequentieverschuiving te behouden (Song et al., 2024).
De relatie tussen de frequentie, massa- en temperatuursverandering voor de mass- en temperature-modi wordt wiskundig weergegeven in vergelijking 5.a en 5.b respectievelijk:

Δf = λ

⋅ ΔT + λ

⋅ ΔT + λ
⋅ ΔT + λ
⋅ Δm | [5. a]

Δf = λ

⋅ ΔT

+ λ
⋅ ΔT

+ λ
⋅ ΔT + λ
⋅ Δm | [5. b]
In deze vergelijkingen zijn de λ-waarden constante coëfficiënten die de karakteristiek van het kristal in de gebruikte modi beschrijven. Δf en Δf zijn de gemeten frequentieverschuivingen van respectievelijk de mass-mode en de temperature-mode. ΔT is de verandering in temperatuur, en Δm is de verandering van de massa van het kristal.
Te zien is dat elke frequentie afhankelijk is van twee variabelen: de massa en de temperatuur

T-f karakteristiek B-mode en 3de harmonische C-mode

26

Kalibratie
Om deze methode toe te kunnen passen, moeten de coëfficiënten vooraf bepaald worden via kalibratie. Voor het bepalen van λ, λ, en λ wordt het kristal in een oven geplaatst, waarbij de temperatuur gecontroleerd wordt verhoogd. Tegelijkertijd worden de frequenties van beide resonantiemodi gemeten. Op de meetdata wordt een derdegraads polynoom gefit, waarbij de coëfficiënten direct worden afgeleid. De constante term van de polynoom vervalt, aangezien de berekening enkel op de veranderingen in frequentie betrekking heeft.
De coëfficiënt λ, die de massa-afhankelijkheid beschrijft, kan afzonderlijk worden bepaald of afgeleid uit eerder geformuleerde massa-frequentierelaties, zoals in vergelijking 4.a.

Metingen
Bij metingen wordt gebruikgemaakt van het verschil tussen de twee frequentiemetingen, Δfₘ − Δfₜ. Deze combinatie levert een vergelijking (vergelijking 5.c) waarin de massa-afhankelijkheid wegvalt en alleen temperatuurafhankelijkheid overblijft. Door deze vergelijking op te lossen, wordt de temperatuurverandering ΔT bepaald.

ΔT

+

λ
⋅ λ − λ

⋅ λ

λ
⋅ λ − λ

⋅ λ

⋅ ΔT

+

λ
⋅ λ − λ

⋅ λ

λ
⋅ λ − λ

⋅ λ

⋅ ΔT

+

λ
λ
⋅ λ − λ

⋅ λ

⋅ Δf +

−λ
λ
⋅ λ − λ

⋅ λ

⋅ Δf = 0 | [5. c]

Tot slot wordt deze ΔT teruggevoerd in vergelijking 5.d, waarin enkel de massaterm behouden blijft. Op deze manier kan de massa die op het kristaloppervlak is afgezet worden bepaald, onafhankelijk van temperatuurfluctuaties.

Δm =

Δf − λ

⋅ ΔT + λ

⋅ ΔT + λ
⋅ ΔT
λ
| [5. d]

Rekentijd
Het oplossen van derdegraads polynomen kost relatief veel computerkracht. Omdat de meetwaarden tijdsgevoelig zijn, moet hier rekening mee gehouden worden bij het kiezen van de processing module. In dit ontwerp zal deze berekening gedaan worden door een desktopcomputer, met meer dan genoeg rekenkracht en zal dit dus geen probleem vormen.

Testprogramma Excel
Om te beoordelen of de methode in de praktijk toepasbaar is, is het algoritme in Excel geïmplementeerd. Met behulp van data verkregen via een netwerkanalysator is het gelukt om de temperatuur van het kristal af te leiden op basis van de frequentieverschuivingen van twee resonantiemodi. Deze test is uitgevoerd zonder verandering in massa, omdat dit de test enorm complex zou maken.

### 5.4 HOE VEEL VERSCHILLEN DE EIGENSCHAPPEN TUSSEN KRISTALLEN VAN DEZELFDE

PRODUCENT, VERSCHILLENDE BATCHES EN BINNEN DE BATCH?
De vraag in hoeverre de eigenschappen van SC-cut kristallen variëren tussen verschillende batches of zelfs binnen dezelfde batch is op dit moment moeilijk te beantwoorden. Er is tot nu toe geen systematisch onderzoek gedaan naar de spreiding van bijvoorbeeld de resonantiefrequentie, de temperatuurafhankelijkheid of de kwaliteit van de verschillende modi tussen meerdere kristallen van één fabrikant.

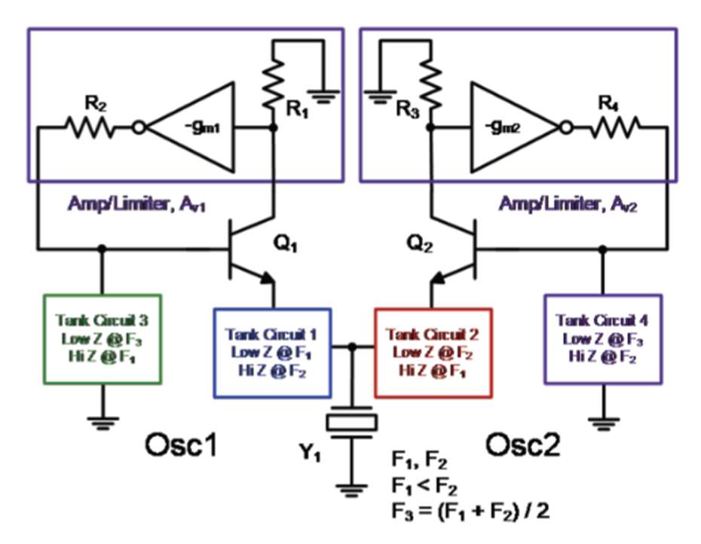
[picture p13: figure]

27

Het belang van deze vraag ligt vooral bij de kalibratiestrategie. Als blijkt dat de eigenschappen van kristallen sterk uiteenlopen, kan dit betekenen dat elke eenheid afzonderlijk gekalibreerd moet worden. Dit is logistiek ongunstig, maar geen fundamenteel probleem: het beïnvloedt enkel de productiekosten of -tijd, niet de werking of haalbaarheid van het systeem zelf. Daarom wordt deze vraag doorgeschoven naar een latere fase van het project. In een toekomstig experiment met een functionerend proof-of-concept zal een populatie kristallen worden geanalyseerd op spreiding in temperatuur- en frequentierespons.
Op basis van die data kan worden bepaald of een eenmalige generieke kalibratie volstaat, of dat per stuk individuele kalibratie noodzakelijk is.

### 5.5 HOE KUNNEN TWEE RESONANTE FREQUENTIES GELIJKTIJDIG GEMETEN WORDEN?

Om de dual-mode temperatuur compensatie mogelijk te maken moet de frequentie van twee resonante modi gelijktijdig gemeten worden.

### 5.5.1 Dual-oscillator

In het PID was ervoor gekozen om een dual-oscillator ontwerp te realiseren (Wardenaar F., 2025). Deze keuze was destijds goed onderbouwd en gebaseerd op literatuur en voorbeelden van bestaande ontwerpen. Echter, in de praktijk bleek deze benadering door simulatieresultaten en praktische afwegingen toch niet geschikt voor deze toepassing.
Het basisidee achter het ontwerp is twee standaardoscillatoren (zoals Clapp-, Colpitts- of Pierce-oscillatoren) in parallelle configuratie. Deze laten het kristal gelijktijdig met verschillende frequenties oscilleren. Door middel van frequentie-selectieve filters zouden deze oscillatoren elkaar niet beïnvloeden. Figuur 5-2 toont een high level voorbeeld van zo’n configuratie.

Figuur 5-2: Dual oscillator diagram (Sandia, 2021)
Positieve eigenschappen
Het ontwerp had enkele duidelijke voordelen:
- De schakeling is in de basis relatief eenvoudig opgebouwd met weinig componenten.
- Het principe is helder en aantrekkelijk vanwege de schijnbare eenvoud van implementatie.
- Er zijn veel (10+) bronnen beschikbaar waarin kristaloscillatoren worden aangestuurd op meerdere modi – hoewel dit niet altijd in het kader van QCM-toepassingen is.

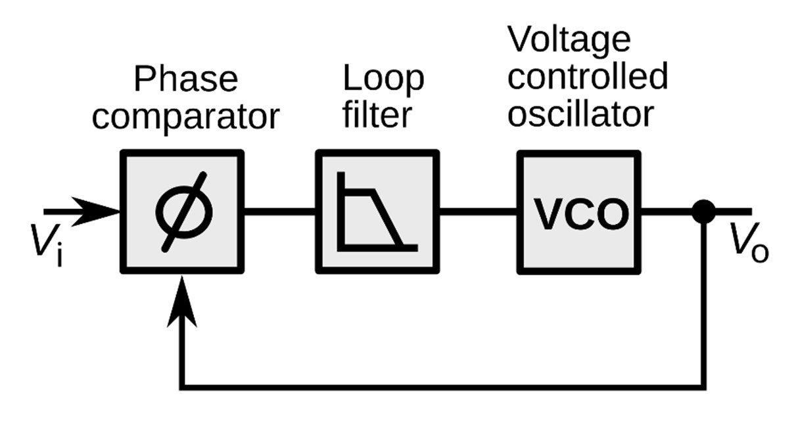
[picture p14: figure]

28

Problemen in de praktijk
Toch bleken er in de simulaties en analyses aanzienlijke problemen:
- Het ontwerp is lastig af te stemmen. De twee oscillatoren beïnvloeden elkaar ondanks de filters, en streven ernaar om op dezelfde frequentie te oscilleren.
- Vanwege de frequentieverschuiving van 5% over de levensduur van het kristal (zie eis 2.6), is het risico groot dat de oscillator spontaan “verspringt” naar de andere modus. Dit zou betekenen dat het systeem opnieuw moet worden afgestemd door de gebruiker. Dit is onwenselijk omdat het systeem erg gevoelig is, en met vier variabele filters, zou dit veel tijd en moeite kosten.
- Bovendien is het wiskundig lastig te modelleren. Waardoor het lastig is theoretisch te voorspellen wat de gewenste waarden zijn.
Op basis van deze bezwaren is uiteindelijk besloten om het dual-oscillator ontwerp niet te implementeren in de uiteindelijke versie van het systeem.

### 5.5.2 Phase-locked loop

Het systeem in designs gebaseerd op het principe van een Phase-Locked Loop (PLL). Dat is een regelsysteem waarbij de uitgangsfrequentie van een spanningsgestuurde oscillator (VCO) automatisch wordt geregeld op een ingangssignaal (Figuur 5-3: PLL-diagram (Wikipedia, 2025)). In het basisprincipe geldt dat het systeem het faseverschil tussen het ingangs- en uitgangssignaal op 90 graden probeert te houden. Hiermee houdt het de twee frequenties gelijk.

Figuur 5-3: PLL-diagram (Wikipedia, 2025)
In het artikel van Ferrari et al. wordt een PLL-systeem beschreven waarbij het uitgangssignaal wordt teruggekoppeld naar het kristal (zie het HLD in Figuur 5-4: High level design). Op deze manier zal de ingangsfrequentie altijd gelijk zijn aan de uitgangsfrequentie. Dit maakt deze implementatie bijzonder, omdat hierdoor namelijk uitsluitend op fase geregeld. Wanneer het kristal resoneert, veroorzaakt dit een faseverschuiving in het teruggekoppelde signaal. De PLL stuurt het systeem zodanig aan dat deze verschuiving 90 graden bedraagt, waardoor de uitgangsfrequentie automatisch de resonantiefrequentie van het kristal volgt. Deze frequentie wordt vervolgens gemeten met een frequentieteller, waarmee de resonantie van het kristal kan worden bepaald. Dit werkt pas wanneer het systeem een “lock” heeft, wat wil zeggen dat de resonantie gevonden is en gevolgd wordt. Het PLL-deel van dit systeem wordt twee keer toegepast, zodat twee resonanties gemeten kunnen worden.

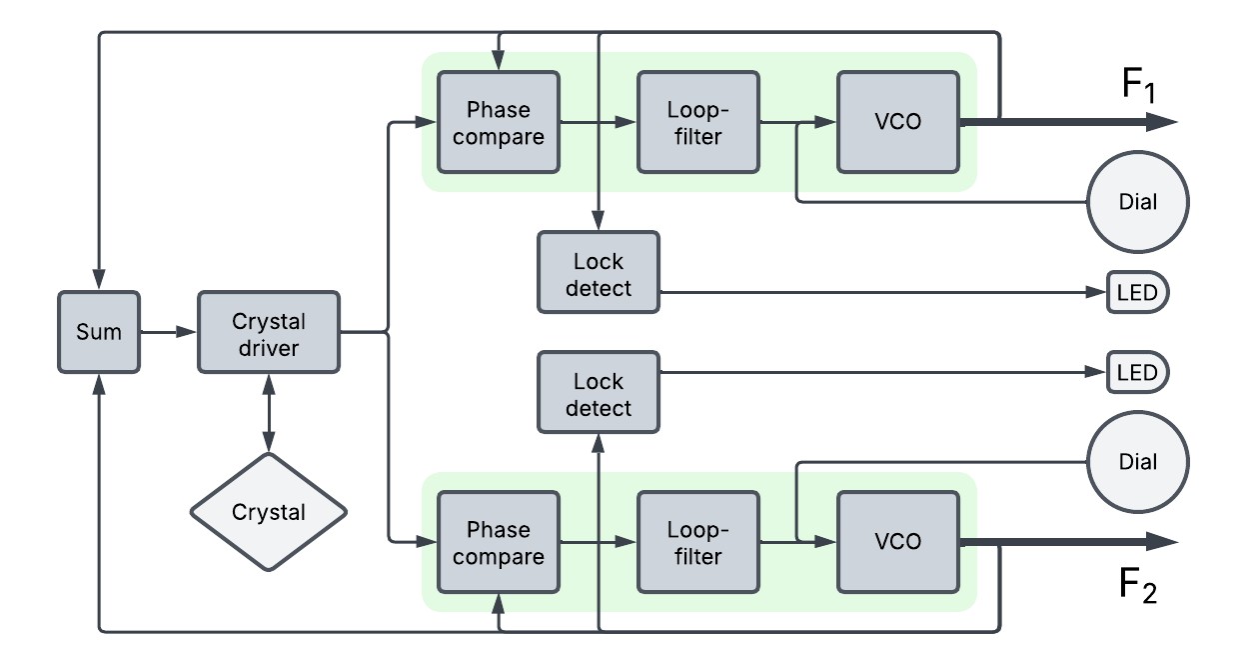
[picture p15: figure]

29

Figuur 5-4: High level design
Het regelsysteem kan pas locken op een resonantiefrequentie wanneer de VCO-frequentie zich al dicht in de buurt daarvan bevindt. Om het systeem naar een resonantiepunt te leiden, kan de gebruiker handmatig de VCO-frequentie instellen met een draaiknop. Dit is essentieel omdat de resonante frequenties niet op dezelfde frequentie blijven. Zodra het systeem een lock bereikt, wordt dit gedetecteerd door de lock-detectieschakeling, die een LED op het voorpaneel inschakelt als visuele bevestiging.

### 5.5.3 Voordelen van een PLL-oplossing

Oorspronkelijk werd de keuze voor een PLL-gebaseerde oplossing niet overwogen. Daarvoor waren destijds meerdere redenen. Ten eerste werd een PLL-systeem beschouwd als een veel complexer geheel met veel afzonderlijke componenten, wat de implementatie onnodig ingewikkeld leek te maken. Daarnaast was er op dat moment geen literatuurbron beschikbaar die een dergelijke oplossing toepaste binnen een dual-mode oscillatorconfiguratie. Het idee werd enkel als suggestie aangereikt door de stagebegeleider en was verder niet technisch uitgewerkt of onderbouwd. Tot slot was de werking van een PLL op dat moment nog onvoldoende begrepen, waardoor de technische uitdaging werd overschat.
Naarmate het project vorderde en de kennis over PLL-systemen toenam, werden ook de voordelen van deze aanpak duidelijk. Een belangrijk voordeel is het instellen van de oscillatoren: dit kan veel eenvoudiger worden uitgevoerd, bijvoorbeeld met slechts één draaiknop per mode. Bovendien biedt een PLL-systeem de mogelijkheid om een 'lock-indicatie' te genereren, waarmee bevestigd kan worden dat het systeem correct is afgestemd. Ook bleek de PLL-configuratie aanzienlijk minder gevoelig voor componentafwijkingen, wat het ontwerp robuuster maakt en het ontwikkelproces vereenvoudigt. Ten slotte bleek dat deze oplossing zou werken over een groot frequentiebereik, wat veel flexibiliteit zou bieden met de gebruikte modi. Hierdoor hoeft de hardware niet aangepast te worden bij het wisselen van modi.
Het omslagpunt kwam toen er uiteindelijk wel een publicatie werd gevonden waarin een PLL-benadering succesvol werd toegepast in een vergelijkbaar dual-mode oscillatiesysteem (Ferrari et al., 2008). Deze vondst maakte de aanpak aanzienlijk aantrekkelijker en leidde ertoe dat de

30

eerder gekozen dual-oscillatorbenadering definitief werd losgelaten ten gunste van het PLL-ontwerp.

31

## 6 TECHNISCH ONTWERP

Dit hoofdstuk presenteert het resultaat van de technisch-ontwerpfase van het project. Binnen deze fase zijn belangrijke mijlpalen behaald: het opstellen van het elektrisch schema, het ontwerpen van het PCB, het uitvoeren van simulaties en het uitwerken van een BOM. Deze bestanden worden samen met dit document geleverd. Voor meer informatie hierover, zie bijlage F.
In deze fase is ook een testplan gemaakt voor de fase “Technische tests”. Dit plan is te vinden in paragraaf 7.1.1.
De structuur van dit hoofdstuk volgt de opbouw van het high-level ontwerp. Elk functioneel blok wordt afzonderlijk besproken: de kristalaansturing, de fasevergelijker, de lock detectie, het loopfilter, de spanningsgestuurde oscillator (VCO) en de optelschakeling. Waarna enkele algemene eigenschappen van het ontwerp besproken, zoals signaal integriteit en ontkoppeling. Tot slot zal de realisatie kort besproken worden.

### 6.1 KRISTALAANSTURING

Vanwege de ontwerpvoorwaarde dat het kristal aan wordt aangesloten met één geaarde BNC-connector, wordt gebruikgemaakt van de serieresonantie. In deze opstelling is het kristal met slechts een elektrode verbonden met de schakeling. Bij serieresonantie heeft het kristal zijn laagste impedantie bij de resonantiefrequentie. Dit wordt benut door het kristal op te nemen in een niet-inverterende versterkerconfiguratie, waarbij het kristal de rol vervult van de impedantie die normaal met aarde is verbonden (zie de bovenste helft van Figuur 6-2). Formule 6.a laat de overdracht van deze schakeling zien, waaruit af te leiden is dat de versterking groter is bij een kleinere kristalimpedantie. Op deze manier worden de resonante frequenties, de punten waar de impedantie het laagst is, versterkt.

V
V

= 1 +

Z

Z

[6. a]

Hierbij is Z de feedbackimpedantie en Z de kristalimpedantie. V & Vzijn de in- en uitgangsspanningen.
Het systeem wordt geregeld op 90 graden faseverschuiving. Iets waar kristal en bijbehorende elektronica voor zouden zorgen als het kristal serie-resonant is. Uit simulaties bleek echter dat bij hogere orde harmonischen, zoals de derde harmonische (10MHz), het kristal slechts enkele graden faseverschuiving veroorzaakt (Figuur 6-1), wat onvoldoende is voor een lock. Dit effect wordt veroorzaakt door de parasitaire capaciteiten van het kristal en de verbonden kabel.

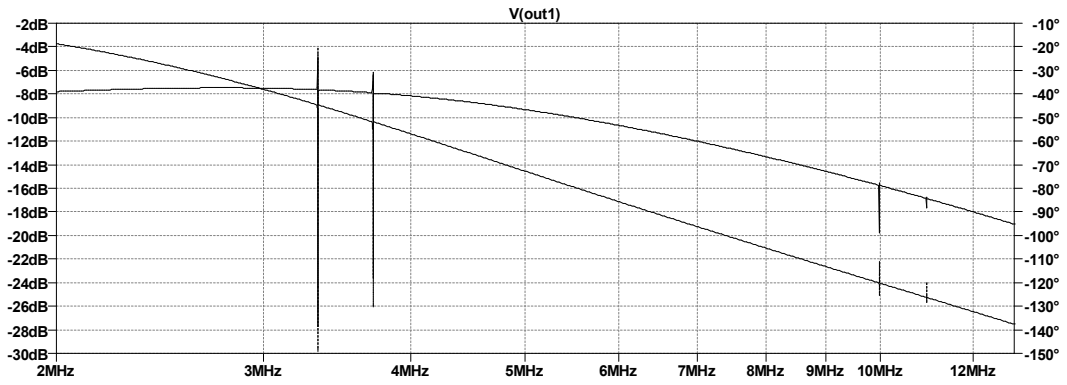
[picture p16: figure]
2MHz; 3MHz; 4MHz; 5MHz; 6MHz; 7MHz; 8MHz; 9MHz 10MHz; 12MHz; -10° V(out1)

32

Figuur 6-1: Frequentierespons enkele versterker [Doorgetrokken: Amplitude, Stippel: Fase]
Om dit probleem te verhelpen, wordt een tweede, parallelle versterker gebruikt. In plaats van een kristal bevat deze versterker een capaciteit C

gelijk aan de parasitaire capaciteit (Figuur 6-2).

Figuur 6-2: Capaciteit compensatie (Ferrari et al., 2008)
Zo wordt een respons gecreëerd die identiek is aan die van de kristalversterker—behalve bij de resonantiepunten. Het verschilsignaal van deze signalen bestaat slechts uit de resonante frequenties (Figuur 6-3). Alle resterende frequenties worden sterk gedempt. De fase van het verschilsignaal verschuift bij elke resonante mode 180 graden, waardoor het altijd een faseverschil van 90 graden passeert, en een lock kan behalen.

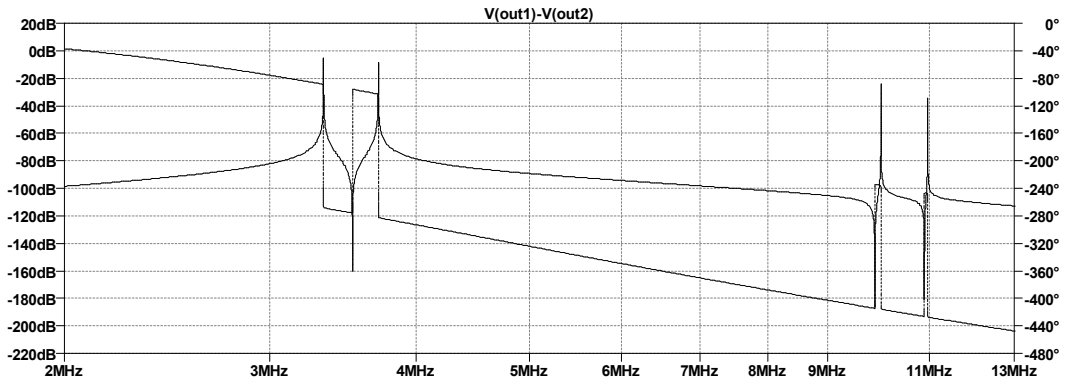
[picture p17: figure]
2MHz; 3MHz; 4MHz; 5MHz; 6MHz; 7MHz; 8MHz; 9MHz; 11MHz; 13MHz; 0° V(out1)-V(out2)

33

Figuur 6-3: Frequentierespons verschilsignaal (let op y-as) [Doorgetrokken: Amplitude, Stippel: Fase]

### 6.2 FASEVERGELIJKER

Het faseverschil tussen het VCO-signaal en het signaal van het kristal wordt bepaald door deze signalen met elkaar te vermenigvuldigen. Daarbij ontstaat een DC-component aan de uitgang die evenredig is met de faseafwijking ten opzichte van 90 graden. Wanneer de signalen exact 90 graden uit fase zijn, is deze DC-component nul.
Elke fasevergelijker bestaat uit een analoge multiplier-IC, die het verschil tussen de signalen op de X+ en X− ingang vermenigvuldigt met het verschil tussen Y+ en Y− ingang. Dit maakt het mogelijk om het verschilsignaal van de kristalaansturingstap te vermenigvuldigen (zie paragraaf 6.1).

### 6.3 LOCK-DETECT

De lock-detect schakeling wordt schematisch weergegeven in Figuur 6-4.

Figuur 6-4: Lock-detect blokschema
De lock-detectschakeling maakt gebruik van hetzelfde analoge multiplier-IC als de fasevergelijker. In dit geval wordt het kristalsignaal eerst 90 graden in fase verschoven voordat het de multiplier binnenkomt. Wanneer de PLL in lock is, levert dit een DC-offset op aan de uitgang van de multiplier. Deze spanning wordt vervolgens gefilterd met een low-pass-filter (LPF) en aangeboden aan een comparator. De comparator vergelijkt deze waarde met een instelbare referentiespanning. Zodra de drempel wordt overschreden, schakelt de comparator een LED op het voorpaneel in, zodat de gebruiker direct kan zien dat de PLL in lock is.

### 6.4 LOOP-FILTER

Het loopfilter speelt een cruciale rol in een PLL. Het filtert het uitgangssignaal van de fasevergelijker en bepaalt daarmee de dynamiek van het regelsysteem. Het zorgt ervoor dat het

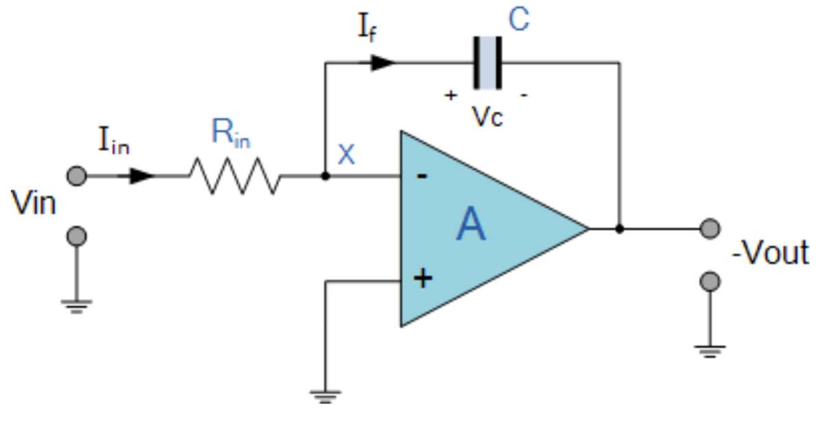
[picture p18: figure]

34

hoogfrequente VCO-signaal geblokkeerd wordt, terwijl langzamere afwijkingen worden doorgelaten om de VCO bij te sturen. Hiermee beïnvloedt het filter de stabiliteit, reactietijd en onderdrukking van faseruis binnen de PLL.

### 6.4.1 Integratorschakeling

Het loopfilter in de PLL is een integratorschakeling. Deze bestaat uit een opamp met een condensator in de terugkoppellus (Figuur 6-5).

Figuur 6-5: Integratorschakeling(Op-amp Integrator, 2022)

V = −

1
RC

⋅ V

dt | [6. b]

De werking van deze schakeling wordt beschreven door Formule 6.b. Hieruit blijkt dat het product van de ingangsimpedantie R en de capaciteit C bepaalt hoe snel de uitgangsspanning V verandert. Dit bepaalt op zijn beurt hoe snel de regellus kan reageren op een foutsignaal. Een hoge regelsnelheid is hierbij gunstig, omdat hiermee de ruis van de VCO kan worden onderdrukt.

### 6.4.2 Dempen van de regellus

Omdat een pure integrator in combinatie met de fasevergelijker een ongewenste lusresonantie kan veroorzaken. De fasevergelijker heeft namelijk een integrerende werking: ϕ = ∫ ω()dt Twee integratoren in serie zouden namelijk samen een faseverschuiving van 180 graden veroorzaken, wat bij positieve terugkoppeling kan leiden tot instabiliteit.
Om deze reden wordt in PLL-implementaties standaard een weerstand in serie met de feedback condensator geplaatst. Deze weerstand zorgt voor extra demping van de integrator, waardoor oscillaties worden voorkomen.
In deze schakeling is de serieweerstand uitgevoerd als een instelbare trimmer. Deze staat standaard op nul, maar kan bij het optreden van oscillaties eenvoudig worden aangepast om demping toe te voegen.

### 6.5 VCO

Voor de spanningsgestuurde oscillator (VCO) kon er gekozen worden uit twee oplossingsrichtingen: een lineaire VCO en een digitale VCO. Een lineaire VCO bestaat uit

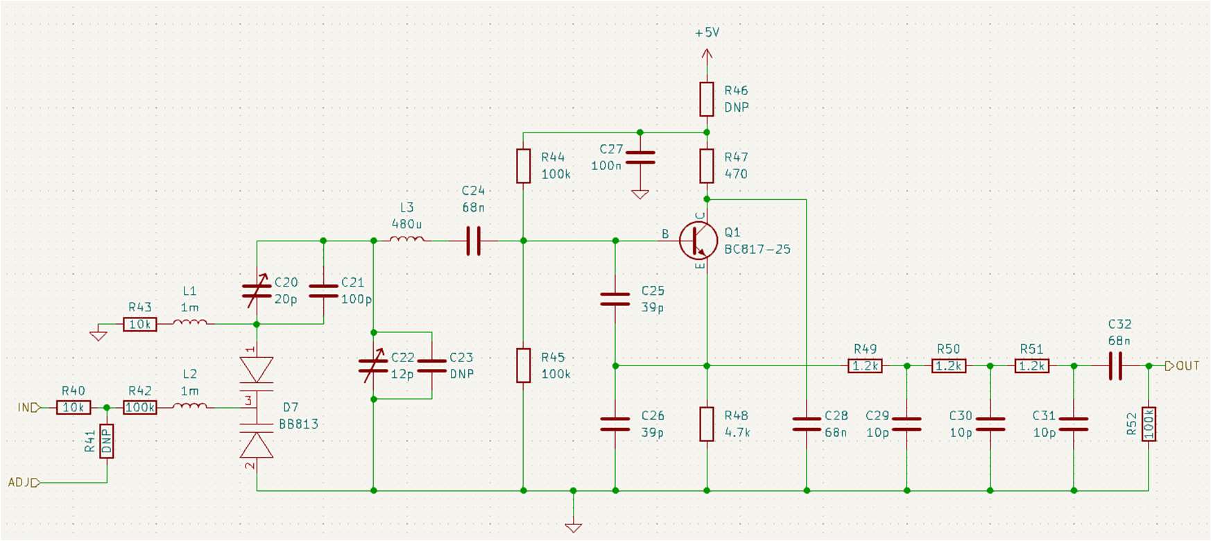
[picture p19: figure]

35

discrete componenten en genereert een sinusachtig uitgangssignaal. Een digitale VCO daarentegen is doorgaans een geïntegreerde schakeling (IC) die blokgolven genereert.
Omdat dit een lineaire PLL is lag de voorkeur bij de lineaire VCO-schakeling. Maar omdat deze schakeling een redelijk complex analoog ontwerp is en de student slechts beperkte ervaring had met het ontwerpen van analoge elektronica, is de keuze gemaakt om beide VCO-opties op de printplaat te implementeren. Door het plaatsen van 0 Ω-weerstanden kan worden geselecteerd welke VCO wordt gebruikt.

### 6.5.1 Digitale VCO

De 74HC7046 is een veelgebruikte IC binnen PLL-toepassingen en bevat een interne fasevergelijker, lock-detector en VCO. Het is geselecteerd omdat het de meest populaire IC is, geschikt voor frequenties rond de 10 MHz.
Het IC werkt volledig digitaal en een digitale fasedetector kan door zijn alineairiteit niet overweg kan met een superpositie van twee signalen. Hierdoor kan de ingebouwde digitale fasedetector in het IC niet worden gebruikt.
De uitgang van de VCO levert een blokgolf, die met een reeks RC-filters wordt omgevormd tot een gedempte sinus, zodat deze geschikt is voor verdere verwerking. Het gewenste frequentiebereik wordt ingesteld via een trimmerweerstand.

### 6.5.2 Lineaire VCO

De lineaire variant is gebaseerd op de Clapp-oscillatorschakeling. Deze schakeling bestaat voornamelijk uit passieve componenten, met een enkele transistor als actief element (Ulansky et al., 2009). De frequentie van het gegenereerde signaal is afhankelijk van het product van de inductie en capaciteit. In dit ontwerp wordt er gebruikgemaakt van varicaps om de capaciteit en daarmee de frequentie te moduleren (zie Figuur 6-6). Varicaps zijn condensatoren waarvan de capaciteit proportioneel is van de dc-spanning die erover staat. Door trimmercondensatoren in serie en parallel met de varicaps te plaatsen, kunnen zowel de centerfrequentie als het frequentiebereik worden afgesteld.

Figuur 6-6: Clapp oscillator-schakeling
Als deze schakeling niet gebruikt wordt en zijn in- en uitgangen zijn losgekoppeld, blijft deze nog oscilleren, wat storing op de voeding kan veroorzaken. Om dit te voorkomen, is de voedingslijn los te koppelen met een 0-ohm weerstand.

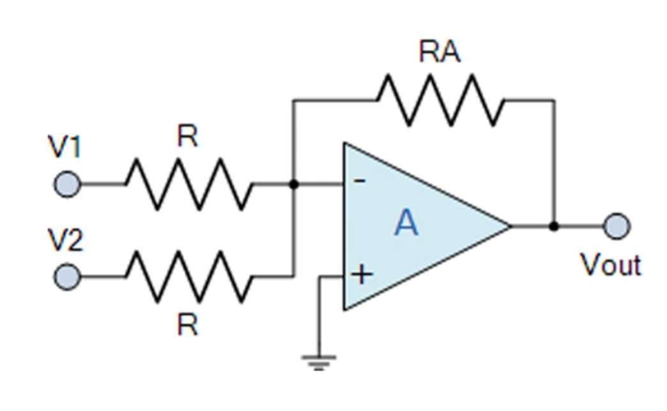
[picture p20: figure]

36

### 6.5.3 Instelmogelijkheden

De kristalfrequenties zullen met 5% zullen verlopen over zijn levensduur. Om te zorgen dat dit binnen het regelbereik van de VCO blijft, kan de center-frequency van dit bereik worden aangepast met een tienslagspotmeter aan het voorpaneel.
Omdat de relatief lange paden mogelijk storing zullen oppikken, zijn deze potmeters met 0-Ohm weerstanden te vervangen door trimmer weerstanden dicht bij de oscillatoren.

### 6.6 OPTELLER

De taak van de opteller is om de signalen van de twee VCO’s bij elkaar op te tellen. De summing-amplifier is een eenvoudige schakeling die deze taak kan vervullen (zie Figuur 6-7). De uitgangsspanning wordt bepaald door vergelijking 6.d, waaruit volgt dat deze spanning evenredig is aan de som van de ingangsspanningen. De versterkingsfactor is afhankelijk van de waarde van weerstand R. In dit ontwerp is R instelbaar gemaakt, zodat de versterking naar behoefte kan worden aangepast.

V = −

R
R

⋅ (V + V

) | [6. d]

Figuur 6-7: Summing-amplifier (Summing Amplifier, 2021)

### 6.7 ALGEMENE ONTWERPEIGENSCHAPPEN

Dit hoofdstuk behandelt ontwerpkeuzes zoals de voedingsstructuur, signaalintegriteit en PCB-afmetingen.

### 6.7.1 Voeding

Externe voeding
Aangezien het ontwerpen van een stabiele voeding buiten de scope van de opdracht valt, is ervoor gekozen het PCB te voeden met een externe labvoeding via bananenstekkers. Hiervoor is een labvoeding vereist die zowel positieve als negatieve spanningen kan leveren.
Zowel de +5 V als de −5 V voedingslijnen hebben elk een indicatie-LED op het voorpaneel, zodat snel visueel kan worden gecontroleerd of de spanning aanwezig is.

Voedingsverdeling op het PCB
De voedingsspanningen V+ en V− worden verdeeld via de derde laag van het vierlaags-PCB. Deze laag is onderverdeeld in twee aparte vlakken voor V+ en V−, die zich uitstrekken tot alle relevante delen van het circuit. De opbouw met brede vlakken zorgt voor een lage impedantie. Bovendien bevindt zich op de derde laag een parallel aardvlak, wat resulteert in een aanzienlijke

37

parasitaire capaciteit tussen de voedings- en aardvlakken. Deze capaciteit helpt bij het onderdrukken van ruis op de voeding.

Ingangsbeveiliging
Om het circuit te beschermen tegen foutieve of schadelijke invoer van voedingsspanningen, zijn verschillende beschermingsmaatregelen getroffen:
- Resetbare zekeringen
Deze zekeringen beschermen tegen kortsluitingen door de stroom te beperken bij overstroom. Ze resetten automatisch nadat het probleem is opgelost, waardoor schade aan het circuit of brandgevaar wordt voorkomen.
- Ferrietkralen
Ferrietkralen filteren hoogfrequente ruis uit de voedingslijnen. Ze werken als impedantie voor hoogfrequente signalen zonder noemenswaardige weerstand te introduceren voor DC-stromen.
- Unidirectionele TVS-diodes (transient voltage suppressor)
Deze diodes bieden bescherming tegen overspanning én tegen spanningen met omgekeerde polariteit. Ze schakelen snel in bij spanningspieken, waardoor gevoelige componenten niet beschadigd raken.
- Ontkoppelcondensatoren bij de voedingsingang
Direct bij de voedingsingang zijn ontkoppelcondensatoren geplaatst om storingen en ruis van buitenaf te onderdrukken voordat deze het circuit binnendringen. Ze vormen een laagimpedant pad naar massa voor hoogfrequente signalen en spanningspieken die via de voedingskabels binnenkomen. Dit voorkomt dat HF-ruis of transiënten zich via de voedingslijnen verspreiden over het PCB. Er is gekozen voor een combinatie van elektrolytische condensatoren (voor lage frequenties en grotere energie-inhoud) en keramische condensatoren (voor hoge frequenties en snelle respons).

### 6.7.2 Ontkoppeling en signaalintegriteit

In het ontwerp is veel aandacht besteed aan ontkoppeling en signaalintegriteit om een stabiele werking van het systeem te waarborgen. Alle geïntegreerde schakelingen zijn voorzien van lokale ontkoppelcondensatoren, die spanningsschommelingen op de voedingslijnen opvangen en hoogfrequente ruis onderdrukken. De versterkende IC’s, zoals operationele versterkers en vermenigvuldigers, zijn via een serieweerstand van 10 Ω aangesloten op de voedingsrails. Deze weerstand beperkt de overdracht van hoogfrequente ruis via de voeding en dempt reflecties, waardoor onderlinge beïnvloeding tussen componenten wordt voorkomen.
Om reflecties op signaalsporen tussen IC’s te onderdrukken, is aan de laagimpedante zijde van deze verbindingen een serieweerstand van 33 Ω geplaatst. Daarnaast zijn de componenten binnen elk functioneel blok zo dicht mogelijk bij elkaar geplaatst. Dit minimaliseert de lengte van stroomlussen en vermindert de kans op inductieve koppeling of overspraak.
Verder is de ruimte onder de spoelen vrijgehouden van koper om ongewenste parasitaire capaciteiten te beperken. Zowel de bovenste als de onderste laag van het PCB zijn voorzien van een aaneengesloten aardevlak, dat strategisch tussen signaalbanen gepositioneerd is om overspraak tegen te gaan. Om de aarding robuust te maken, zijn door het hele PCB structureel

38

geplaatste via’s opgenomen, die de drie aardevlakken onderling verbinden. Deze maatregelen dragen gezamenlijk bij aan een hoge signaalkwaliteit en een betrouwbaar systeemgedrag.

### 6.7.3 PCB-afmetingen

De printplaat heeft een formaat van 159 × 150 mm. Deze afmetingen zijn gekozen zodat het ontwerp past in een standaardbehuizing die vaker wordt gebruikt binnen de ELD-afdeling: de M5501119 (Figuur 6-8). De PCB kan in het kastje worden gemonteerd met behulp van de connectoren die in het voor- en achterpaneel schroeven. De behuizing is vooral voor het uiterlijk. Het PoC zal zonder even goed werken

Figuur 6-8: M5501119 Behuizing (M5501119, n.d.)

### 6.8 REALISATIE

### 6.8.1 PCB

Vanwege tijdsgebrek is de assemblage van de PCB (Figuur 6-9) niet door de student zelf uitgevoerd, maar is deze taak uitbesteed aan een collega. De SMD-componenten zijn geplaatst en gesoldeerd met behulp van een dampoven. De THT-componenten zijn vervolgens handmatig gesoldeerd.

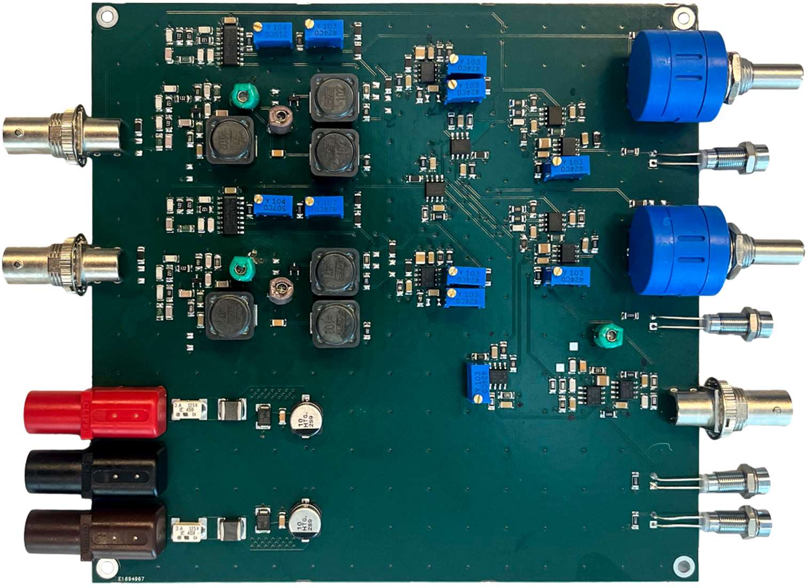
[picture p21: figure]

39

Figuur 6-9: Gerealiseerd PCB

### 6.8.2 Behuizing

De behuizing van het systeem is op dit moment nog niet volledig gerealiseerd. De metalen panelen aan de voor- en achterkant zijn nog niet bewerkt. Dit ook als gevolg van tijdsgebrek. Hierdoor is het tijdens de testfase niet mogelijk om de PCB in een definitieve behuizing te plaatsen.
Er wordt echter verwacht dat het ontbreken van een behuizing tijdens de testfase geen significante invloed zal hebben op de prestaties van het systeem. Het wordt ingeschat dat het ontwerp niet gevoelig is voor elektromagnetische interferentie.

40

## 7 VALIDATIE

Dit hoofdstuk zal ingaan op de validatiefasen: Technische tests, Functionele tests en Acceptatie tests. De vooraf gemaakte testplannen worden hier beschreven.
Op het moment van schrijven bevindt het project zich in de technische testfase. Er zal daarom alleen van de technische tests de uitvoering en resultaten besproken worden.

Tabel 7-1: Testniveau overzicht
Testniveau | Status | Doelstelling
| Technische tests | | Uitgevoerd | Verifiëren of de subsystemen technisch correct
functioneren (bijv. signaal generatie, voedingspanningen).
Functionele tests | Geformuleerd | Controleren of het systeem als geheel de
gespecificeerde functies los van elkaar uitvoert.
Acceptatietests | Geformuleerd | Beoordelen of het systeem als geheel de
gespecificeerde functies tegelijkertijd uit kan voeren.

### 7.1 TESTPLANNEN

Tijdens de ontwerpfasen zijn er testplannen opgesteld. In dit hoofdstuk staan deze beschreven.

### 7.1.1 Technische tests

In deze testfase wordt de basisfunctionaliteit van het PoC beproefd.
Doordat het een geregeld systeem is, is het lastig om de verschillende modules los van elkaar te evalueren. Door een gebrek aan gemakkelijke testmogelijkheden en tijd om deze uit te voeren worden alleen de voeding en de VCO beproefd. In een later stadium zijn tests bedacht voor alle technische modules (zie 7.2.3 Vervolgtests).

Voedingstest
Het doel van deze test is om te controleren of het systeem correct functioneert bij het inschakelen van de voeding. Daarbij wordt gekeken of het stroomverbruik binnen de verwachte grenzen blijft, of componenten niet oververhit raken, en of de voedingsspanningen correct worden geleverd aan alle onderdelen.
Voordat deze test kan worden uitgevoerd moet de PCB volledig geassembleerd zijn en moet deze visueel gecontroleerd zijn op soldeerfouten.
Op basis van de datasheets van de gebruikte componenten is het verwachte totaalverbruik van het systeem in rusttoestand als volgt:

Tabel 7-2: Berekening stroomverbruik
COMPONENT AANTAL MAX. RUSTSTROOM PER STUK TOTAAL BRON
OPA656 | 8 | 17 mA | 136 mA | (OPA656 Datasheet, 2024)
AD836 | 4 | 25 mA | 100 mA (AD835 Datasheet,
| | | | n.d.)

41

74HC7046 | 2 | 8 mA | 16 mA | (CD74HC7046A
| | | | Datasheet, 2003)
TOTAAL | | | 252 mA
Een marge van 48 mA is gereserveerd voor overige verbruikers en meetonnauwkeurigheden. De voeding wordt daarom ingesteld op een limiet van 300 mA.
Bij het inschakelen van de voeding worden de volgende punten op volgorde getest:

### 1. De voeding blijft in zijn spanningsgelimiteerde mode 2. De voeding indicator-LED’s staan aan 3. De spanning op de voedingspootjes van de IC’s komen overeen met de verwachting

(meting door multimeter)

### 4. De componenten zijn na 15 minuten niet warmer dan 50 °C (meting door

warmtebeeldcamera)
Mits het PoC aan al deze punten voldoen, slaagt de test.

Oscillatortests
Het doel van deze test is om te controleren of de oscillatoren op de print correct functioneren, een stabiel uitgangssignaal genereren en instelbaar zijn via de bijbehorende potmeters. De test richt zich op zowel de digitale als de lineaire VCO’s die op de PCB zijn geplaatst.
Voordat deze test kan worden uitgevoerd, moet de PCB volledig geassembleerd zijn en succesvol de voedingstest hebben doorlopen.
De test bestaat uit twee delen: het testen van de digitale VCO’s en het testen van de lineaire VCO’s. De testprocedure is voor beiden hetzelfde.
Teststappen:
1. Plaats de benodigde 0-ohm weerstanden om de gewenste VCO te activeren.
2. Verbind de uitgang van de VCO met een oscilloscoop via een coaxkabel.
3. Schakel het systeem in.
4. Verander de frequentie met de bijbehorende potentiometer.
5. Observeer het uitgangssignaal op de oscilloscoop. Succescriteria:
- Het uitgangssignaal is zichtbaar op de oscilloscoop.
- Het signaal heeft een sinusachtig karakter (licht vervormde sinusvorm).
- De frequentie verandert bij draaien aan de potentiometer.
- De frequentie kan minstens gevarieerd worden tussen 1MHz en 15 MHz.
Als de digitale en/of de lineaire VCO’s voldoen aan bovenstaande succescriteria, is de oscillatiefunctie van het systeem technisch gevalideerd. Bij afwijkingen dient verdere analyse te worden uitgevoerd, met nadruk op soldeerverbindingen, voedingsspanningen en PCB-layout.

42

### 7.1.2 Functionele tests

T2.1, T2.2, T2.3: PLL lock test
Het doel van deze tests is om te verifiëren of de PLL-systemen correct functioneren en in staat zijn een stabiele lock te verkrijgen op de gewenste frequenties. Deze test wordt uitgevoerd op drie niveaus: de eerste harmonische van de B-mode, de derde harmonische van de C-mode, en de dual-mode configuratie waarbij beide PLL-kringen gelijktijdig actief zijn.
Voordat deze test kan worden uitgevoerd, moet de voedingstest en de oscillatortest met succes zijn afgerond. Ook moeten enkel de gewenste VCO’s ingeschakeld zijn met 0-ohm weerstanden.
De single-mode tests volgen dezelfde stappen en hebben dezelfde testcriteria. De dual-mode test is simpelweg de twee voorgaande tests gelijktijdig uitgevoerd. Hiervoor dienen de twee VCO’s ingeschakeld te worden.
Teststappen:

### 1. Schakel één van de twee PLL-kringen in door de VCO aan te sluiten met de 0-ohm

weerstanden.

### 2. Maak de capaciteit van de compensatie trimmercondensator gelijk aan de capaciteit

van het aangesloten kristal en kabel.
3. Verbind een oscilloscoop probe met de multiplier output.
4. Monitor tegelijkertijd het uitgangssignaal van de VCO met een frequentieteller.

### 5. Stel met de potmeter de VCO in op een frequentie dicht bij de gewenste

resonantiefrequentie van het kristal.
6. Observeer het gedrag van de multiplier output en de frequentie. Succescriteria:
- Het outputsignaal van de lock-detector-multiplier vertoont een duidelijke DC-component.
- Het lock-detectie lampje gaat aan wanneer er een lock optreedt.
- De uitgangsfrequentie van de VCO blijft stabiel met slechts enkele tientallen hertz aan variatie.
- Er is geen overmatige ruis (<±100Hz) zichtbaar.
- Bij het opwarmen van het kristal, door zijn behuizing vast te houden, veranderd de frequentie.
Als in alle drie de testfasen een stabiele lock wordt verkregen onder de gespecificeerde voorwaarden, wordt de PLL-functionaliteit als succesvol gevalideerd beschouwd.

T2.4: Temperatuurcompensatietest
(Dit testplan was geformuleerd in het PID (Wardenaar F., 2025))
Om de effectiviteit van de temperatuurcompensatie te testen, wordt de QCM in een oven geplaatst waarin de temperatuur stapsgewijs wordt verhoogd van 20°C tot 100°C. Tijdens deze

43

test wordt de gecompenseerde massawaarde continu bijgehouden. De test wordt als succesvol beschouwd wanneer de gecompenseerde frequentie minder dan 0,2 ppm/°C verandert over het gehele temperatuurbereik.

T2.5: Massameettest
(Dit testplan was geformuleerd in het PID (Wardenaar F., 2025))
Voor de evaluatie van de massameting wordt de QCM in een opdampopstelling geplaatst. Op een sample wordt een lijn getrokken met een permanente marker, waarna een 1um laag aluminium wordt opgedampt. Vervolgens wordt de marker verwijderd met isopropanol, waardoor een scherpe overgang in de laag ontstaat. De dikte van de opgedampte laag wordt gemeten met een scanning-tunneling-microscope en vergeleken met de door de QCM gemeten waarde. De test is geslaagd wanneer de afwijking kleiner is dan 0,01 nm (zie eis Nr. 2.2). Om de betrouwbaarheid te waarborgen, zal deze test minstens drie keer worden uitgevoerd.

### 7.1.3 Acceptatie tests

Dit testplan was geformuleerd in het PID (Wardenaar F., 2025).

T3.1: Temperatuurcompensatie bij opdampen test
Ter verificatie van de algehele prestaties van de QCM wordt een opdamping uitgevoerd met niobium, dat een hoog smeltpunt heeft van 2477 C°. Hierbij zal gedurende 5 minuten met een opdampsnelheid van 0,20 nm/s worden opgedampt. De nauwkeurigheid van de QCM wordt beoordeeld door de gemeten waarde te vergelijken met de werkelijke laagdikte, op dezelfde manier als de vorige test. Deze test is geslaagd wanneer de afwijking minder dan 18 ppm bedraagt. Deze tolerantie is afgeleid uit de eis van 0,2 ppm/°C (eis Nr. 1.1), waarbij wordt aangenomen dat het kristal een maximale temperatuur van ongeveer 90°C bereikt.

### 7.2 TESTRESULTATEN

Tabel 3: Overzicht testresultaten
| Test | Verwacht | Gemeten | Resultaat
T1 | | Technische tests
T1.1 | Stoomverbruik | <300mA | 200mA | Geslaagd*
T1.2 | Warmte | <50 °C | 34.7 | Geslaagd
T1.3 | Spanningsniveaus IC-voeding | Kloppen | Kloppen | Geslaagd
T1.4 | Voeding indicator LED’s | Aan | Aan | Geslaagd
T1.5 | Komt signaal uit VCO’s | Ja | Ja | Geslaagd*
T1.6 | Uitgangssignaal is te sturen met potmeter | ~1MHz- | 86kHz- | Geslaagd*
| | ~15MHz | 15MHz
T2 | Functionele tests
T2.1 | B-mode lock | Ja | Nee | Gefaald
T2.2 | C-mode 3de harmonische lock | Ja | Nee | Gefaald
T2.3 | Dual-mode lock | Ja | - | -
T2.4 | Temperatuurcompensatietest | <0.2 ppm/°C
T2.5 | Massameettest | ±0.02nm | - | -
T3 | Acceptatie tests
T3.1 | Temperatuurcompensatie bij opdampen test | <18ppm | - | -

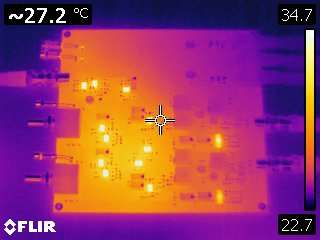
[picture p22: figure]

44

*met bijzonderheden

### 7.2.1 Technische testresultaten

Voedingstest [T1.1, T1.2, T1.3, T1.4]
- Bij het eerste inschakelen bleek de stroomopname hoger dan verwacht. Met behulp van een warmtebeeldcamera werden verkeerd geplaatste componenten geïdentificeerd. Na correctieve herplaatsing daalde het stroomverbruik tot binnen de verwachte grens.
- De actieve componenten (IC’s) warmden tijdens bedrijf merkbaar op, maar bleven ruim onder de limiet van 50 °C (zie Figuur 7-1).
- Met een multimeter is bevestigd dat alle IC’s de correcte spanningen ontvingen. Ook brandde de indicator-LED’s. Hiermee zijn alle onderdelen succesvol van voeding voorzien.

Conclusie:
Na correctie van de foutieve plaatsingen is de voedingstest met succes afgerond.

Figuur 7-1: Warmtebeeld van PCB na 15 minuten aan staan (let op: PCB andersom t.o.v. Figuur 6-9)

Digitale VCO [T1.5, T1.6]
- Het uitgangssignaal van het VCO-IC was periodiek en lag in de verwachte frequentieband. Rond 6 MHz was het signaal echter sterk driehoekig van vorm (zie Figuur 7-2). Dit is het gevolg van onvoldoende filtering. Omdat de twee gekozen frequenties geen harmonischen van elkaar zijn, wordt dit niet als een serieus probleem ingeschat.
- Het ontwerp voorzag in het loskoppelen van de VCO met 0-ohm weerstanden. Er bleek echter geen mogelijkheid om de voeding naar het VCO-IC volledig te onderbreken, waardoor het VCO altijd zou oscilleren en storing zou veroorzaken. Door de

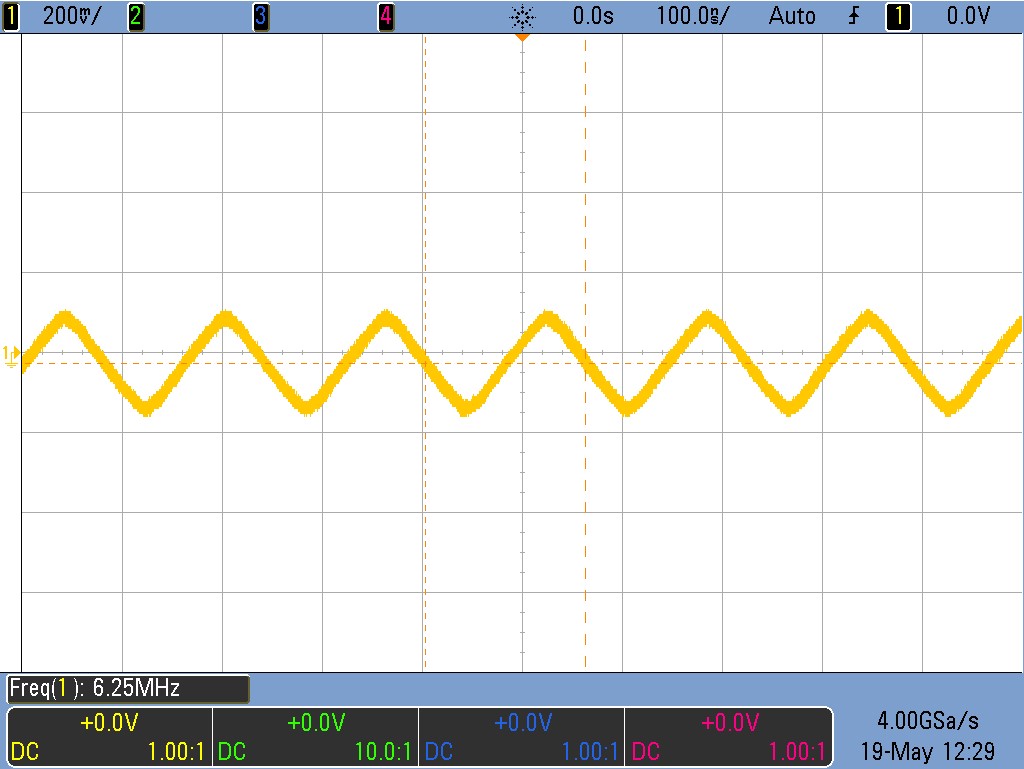
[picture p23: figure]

45

oscillatiecondensator te overbruggen, stopt de IC met oscilleren, en werd dit probleem opgelost.
- Een verdere ontwerpafwijking was dat de potmeter op het voorpaneel aangesloten was op de pin voor frequentiebereik in plaats van de centerfrequentie. Hierdoor beïnvloedde de draaiknop het bereik in plaats van de gewenste frequentiepositie. De centerfrequentie kon echter alsnog worden ingesteld via een trimpotmeter op de print, wat voldoende was voor testdoeleinden.
- Een andere observatie is dat, hoewel het frequentiebereik van 86kHz tot 15MHz gaat, dit verloop exponentieel is. Dit betekent dat het erg lastig is om bij hogere frequenties precieze aanpassingen te maken. Een oplossing hiervoor zou zijn het gebruik van logaritmische potmeters, of de toevoegingen van weerstanden om het instelbereik te verkleinen.

Conclusie:
Ondanks enkele ontwerptekortkomingen functioneerde het digitale VCO-IC zoals verwacht en kon het effectief worden getest.

Figuur 7-2: Scopebeeld VCO uitgangssignaal op 6 MHz

Lineaire VCO [T1.5, T1.6]
- Er was geen uitgangssignaal waarneembaar.
- Onderzoek toonde aan dat de transistor die onderdeel uitmaakt van de oscillator foutief was geplaatst vanwege een fout in de footprint-toewijzing. Dit kon worden opgelost door de transistor gedraaid te solderen.
- Ondanks deze correctie bleef het uitgangssignaal afwezig. De exacte oorzaak hiervan is niet vastgesteld binnen de testtijd.

46

- Omdat het ontwerp slechts vereiste dat één van beide VCO-types functioneerde, werd deze test als niet-blokkerend beschouwd.

Conclusie:
De lineaire VCO gaf geen functioneel signaal, maar gezien de digitale VCO correct functioneerde en voldoende was voor de toepassing, wordt deze test niet als kritisch falen beschouwd.

### 7.2.2 Functionele testresultaten

Single-mode-lock test [T2.1]
- Vanwege de beperkte beschikbaarheid van 6 MHz SC-cut kristallen is voor deze test een 3.3 MHz SC-cut kristal gebruikt.
- De totale parasitaire capaciteit van het kristal en de aangesloten coaxkabel werd gemeten op 90 pF. Om deze capaciteit correct te compenseren is één parallelle condensator verwijderd en is de trimmercondensator handmatig afgesteld.
- De VCO-uitgangsfrequentie is vervolgens zo nauwkeurig mogelijk afgestemd op de verwachte resonantiefrequentie van het kristal, met behulp van de trimmerweerstand. Waarnemingen:
- Er trad geen waarneembare lock op in de buurt van de resonantiefrequentie.
o De lock-indicator LED lichtte niet op.
o De uitgang van de lock-detector multiplier vertoonde geen significante DC-component die reageerde op de frequentieinstelling.
o De frequentie van het VCO-signaal stabiliseerde niet, maar vertoonde variaties in de orde van kiloherzen.
o Het gedrag van het systeem veranderde niet meetbaar in de buurt van de resonantiefrequenties vergeleken met andere frequenties.
Analyse:
- De oorzaak van het uitblijven van lock is nog niet vastgesteld.
- Een mogelijk probleem is dat het kristal door zijn hoge Q-factor, zeer weinig effect heeft net buiten zijn resonantie, wat het invangbereik erg klein kan maken. Mocht dit een probleem zijn kan de Q-factor worden verlaagd met een weerstand in serie met het kristal.
- Een gestructureerde aanpak is opgesteld om het systeem per module te analyseren (zie §7.2.3).
Gevolg:
- Aangezien single-mode lock een vereiste is voor verdere functionele tests, zijn de dual-mode en temperatuurcompensatietests (nog) niet uitgevoerd.

47

Conclusie:
De single-mode lock test is niet geslaagd. Verdere functionele verificatie is afhankelijk van het eerst oplossen van deze blokkade. Verdere diagnose wordt gepland volgens de aanpak in §7.2.3.

### 7.2.3 Vervolgtests

Na het uitblijven van een succesvolle single-mode lock (zie §7.2.2) is besloten het systeem op te splitsen in afzonderlijke functionele blokken. Door de terugkoppellus te onderbreken wordt elk subsysteem afzonderlijk geëvalueerd met externe stimulatie, om zo de oorzaak van het falen te kunnen achterhalen.

Testvoorbereiding
- De uitgang van de VCO wordt losgekoppeld en de bijbehorende connector wordt gebruikt als ingang voor een externe functiegenerator.
- Door het systeem op deze manier open te breken, kunnen blokken worden getest zonder invloed van feedback.
- Alle metingen worden uitgevoerd met een oscilloscoop, functiegenerator en indien nodig een netwerkanalysator.

Opteller Test
Doel: Verifiëren dat de opteller correct de som van twee ingangen produceert.
Methode:
- Twee sinusvormige signalen met gelijke frequentie worden simultaan aangeboden via een functiegenerator.
- De uitgang van de opteller wordt bekeken met een oscilloscoop.
Verwachte resultaat: De uitgangsgolfvorm moet de optelsom zijn van de twee ingangssignalen (zowel amplitude als fase). Op de inverterende ingang is geen signaal zichtbaar. Dit is namelijk een virtueel aardpunt.

Kristalaansturing Test
Doel: Analyseren van de signaalverwerking door de kristalaansturing en compensatieversterker.
Methode:
- Een SC-cut kristal wordt aangesloten.
- Eén ingang van de kristalaansturing wordt via een sweep aangestuurd met een functiegenerator rond de verwachte resonantiefrequentie.
- De uitgangen van zowel de kristalaansturing als de compensatieversterker worden geobserveerd.
- Met de oscilloscoop worden deze signalen ook onderling vergeleken (verschilsignaal via ‘math’-functie).
Verwachte resultaat:
- De amplitude en faseverschuiving van deze signalen ten opzichte van het ingangssignaal moeten vergelijkbaar zijn met de simulaties zoals beschreven in §6.1.

48

- Bij resonantie is een duidelijke faseomslag en amplitudeverandering zichtbaar.

Multiplier Test
Voorwaarde: Alleen uitvoeren indien de bovenstaande tests geslaagd zijn.
Doel: Controleren of de multiplier een detecteerbare DC-component genereert nabij resonantie.
Methode:
- Eén ingang wordt via een sweep over een smal frequentiebereik aangestuurd.
- De uitgang van de multiplier wordt met een oscilloscoop gemonitord.
Verwachte resultaat: Nabij de resonantiefrequentie ontstaat een DC-component in de uitgangsspanning. De maximale waarde wordt geschat op circa 50% van de ingangsamplitude.

Lock-Detect Test
Doel: Evalueren of het lock-detectiesysteem correct werkt.
Methode:
- De uitgang van de multiplier wordt opnieuw gesweept zoals in de vorige test.
- De ingangsspanning van de comparator wordt gemeten.
- Vervolgens wordt gekeken of de comparator-uitgang (en dus de LED) correct schakelt bij overschrijding van de drempelspanning.
Verwachte resultaat:
- Op resonantie stijgt de DC-spanning boven de comparator-drempel.
- De lock-indicator LED schakelt in overeenkomst hiermee.

Loop filter Test
Doel: Verifiëren of het loop filter het gewenste frequentiegedrag vertoont. Methode:
- De module wordt los getest met een netwerk analyzer.
Verwachte resultaat:
- De gemeten frequentierespons moet overeenkomen met het verwachte overdrachtsgedrag (laagdoorlaat met bekende knikfrequentie).

VCO Modulatie Test
Doel: Testen van de gevoeligheid van de VCO voor spanningsvariatie.
Methode:
- De ingang van de VCO wordt aangesloten op een variabele DC-bron.
- De uitgangsfrequentie wordt gemeten met een frequentieteller of oscilloscoop.
- Het effect van de instelweerstanden wordt geëvalueerd.
Verwachte resultaat:
- De uitgangsfrequentie moet mee veranderen met de ingangsspanning.

49

- De mate van frequentieverschuiving moet logisch te relateren zijn aan de ingestelde componentwaarden.

### 7.2.4 Conclusie

Technische tests
De voedingstest verliep succesvol na het corrigeren van verkeerd geplaatste componenten. Het stroomverbruik bleef binnen de verwachte grenzen, alle IC’s ontvingen de juiste spanning en oververhitting werd niet vastgesteld. De VCO-IC werkte grotendeels naar verwachting, ondanks enkele ontwerpbeperkingen. De lineaire VCO bleef zonder uitgangssignaal, maar was niet essentieel voor verdere tests.

Functionele tests
De single-mode lock test mislukte: het systeem vertoonde geen tekenen van lock. Hierdoor zijn de overige functionele tests nog niet uitgevoerd.
Een grondig technisch testplan is opgesteld om de oorzaak te achterhalen. Hierin worden de modules zo veel mogelijk los van de rest beproefd. Het uitvoeren van deze tests betekend dat het project zich weer in de technische testfase bevindt.

50
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

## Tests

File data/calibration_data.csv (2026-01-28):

Temp | Freq_T | Freq_M
99.3 | 6560759.44140625 | 5982640.5810546875
95.4 | 6561045.6220703125 | 5982646.0283203125
90.2 | 6561432.1552734375 | 5982653.431640625
85.2 | 6561815.1904296875 | 5982659.953125
73.2 | 6562801.0751953125 | 5982672.765625
69.4 | 6563174.66015625 | 5982674.2978515625
63.5 | 6563755.2646484375 | 5982676.291015625
60 | 6564084.2412109375 | 5982676.3349609375
57.3 | 6564420.150390625 | 5982675.71875
54 | 6564840.6904296875 | 5982673.984375
50.9 | 6565222.091796875 | 5982671.537109375
46.4 | 6565816.2744140625 | 5982666.3046875
38.9 | 6566882.091796875 | 5982652.259765625
35.8 | 6567371.951171875 | 5982643.953125
33.3 | 6567763.0537109375 | 5982636.384765625
31.2 | 6568038.9345703125 | 5982630.5185546875
29 | 6568438.947265625 | 5982621.2900390625
26.1 | 6568878.5205078125 | 5982609.8388671875
25.5 | 6568985.0966796875 | 5982606.697265625

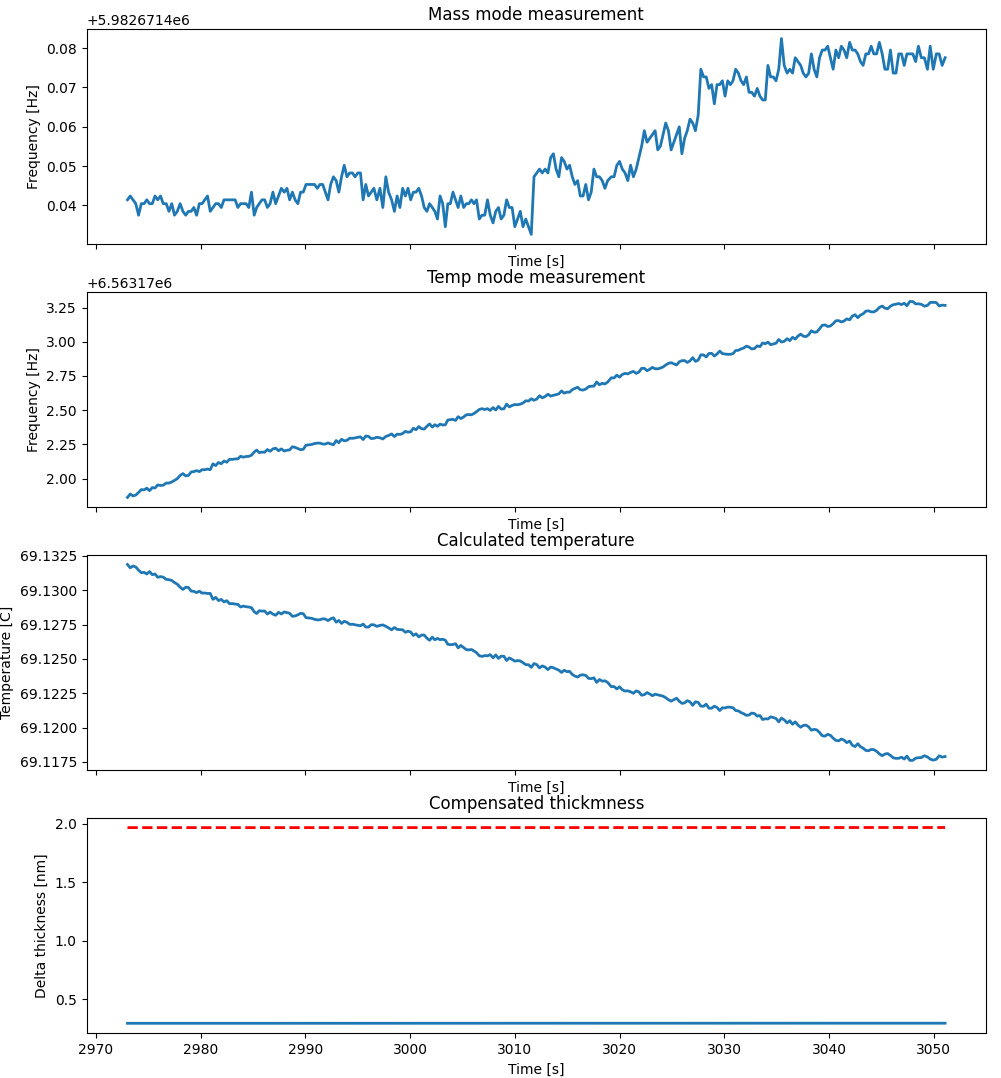
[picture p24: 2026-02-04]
screenshots/calibratie_resultaat_na_verbetering_lijm_3.png

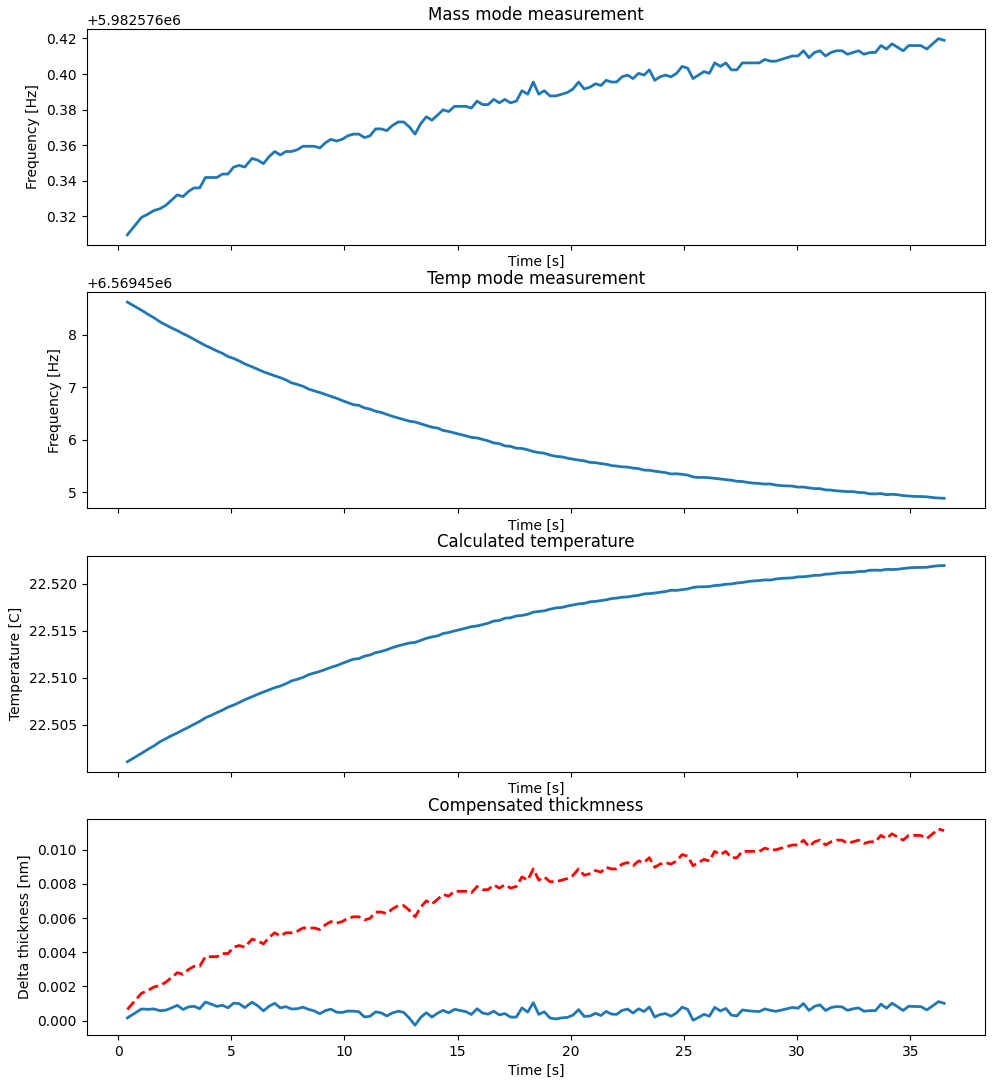
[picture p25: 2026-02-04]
screenshots/QCM_test_11_na_aanpassen_massa_gevoeligheid.png

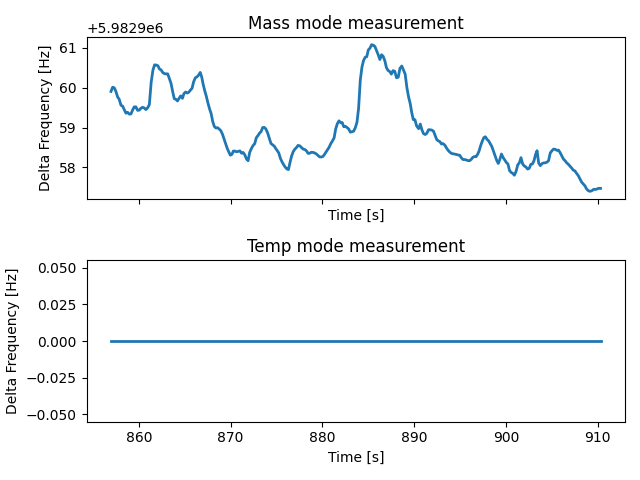
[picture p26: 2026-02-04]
screenshots/QCM_test_5_before_disabling_digital_lines.png

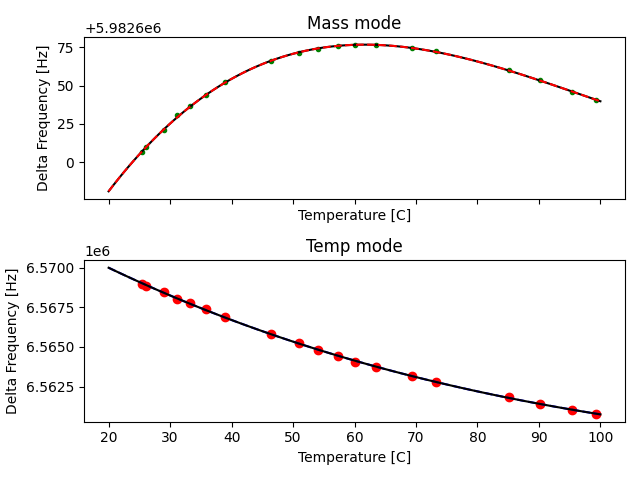
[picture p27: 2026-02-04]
screenshots/calibratie_resultaat_na_verbetering_lijm_2.png

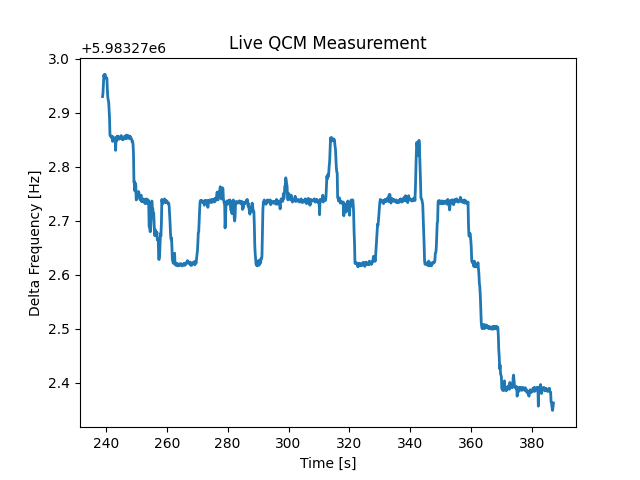
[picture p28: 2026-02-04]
screenshots/QCM_test_2.png

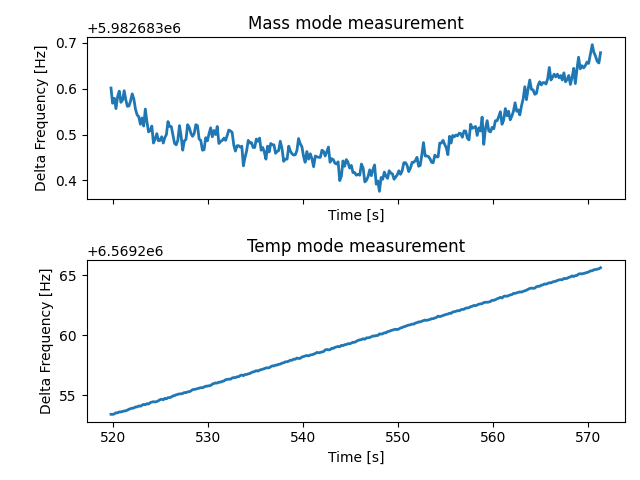
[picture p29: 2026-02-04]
screenshots/QCM_test_8_without_sum-amp.png

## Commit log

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2025-12-22 Add temperature compensation algorithm and related files
    - Implemented TempCompAlgorithm class for temperature compensation calculations.
    - Updated startup.py to utilize the new algorithm for measurements.
    - Added calibration parameters in calParams.csv.
    - Created output.csv for logging measurement results.
    - Enhanced error handling in generate_and_upload.sh.
    [calParams.csv]
2025-12-23 Made the CORDIC's 14-bit again. fixed bugs in the python scripts.
    [calParams.csv, output.csv]
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2026-01-07 Added the PCB design.
    still missing some small stuff before its ready
    [QCM_circuit.PcbDoc, QCM_circuit.SchDoc]
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2026-02-27 FIX the mass and frequency modes were switched in the moving window bit
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2026-03-10 Added IQ measurement functionality to the fpga code. also fixed a bug in the loop filter causing instability at low loop gains
    [output.csv]
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2026-04-30 Refactor QCM package structure and implement QCM interface
    - Deleted obsolete files and cleaned up the QCM package structure.
    - Added new QCM interface implementation in `src/core/QCM_interface.py` for handling measurements and calibrations.
    - Introduced `TempCompAlgorithm` for temperature compensation in `src/processing/TempCompAlgorithm.py`.
    - Moved WagoClient to `src/opcua/wago_client.py` for better organization.
    - Updated `interactive.py` to enforce command line argument for RP IP address.
    - Fixed variable name in `data_plotter.py` for clarity.
    - Created necessary `__init__.py` files for package initialization in core, hardware, opcua, and processing directories.
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2026-06-04 feat(crystal): add apply crystal form endpoint and UI integration
    - Implemented a new endpoint to apply crystal settings immediately after saving.
    - Updated the UI to include a modal for PLL lock failure notifications.
    - Enhanced the crystal settings panel with start frequency inputs and calibration coefficients.
    - Refactored the crystal management functions to streamline loading and applying settings.
    - Added event handling for lock status and auto-updated start frequencies.
    - Increased the maximum startup tries for PLL from 10 to 100 seconds for better reliability.
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2026-06-16 docs(readme): fix inline math delimiters for GitHub rendering
    Replace \( \) with $ $ so inline ΔT and Δm render correctly
    in the GitHub markdown preview.
2026-06-17 feat: auto re-lock, capacitor-adjust mode, Python client, OPC simplification
    - qcm_worker: automatically re-acquire lock if both modes stay unlocked
    >1s during a run (reuses last lock freqs, keeps the measurement reference);
    refactor manual/auto re-lock into _acquire_lock
    - capacitor-adjust mode: emit two static off-resonance tones at (Fm+Ft)/2 and
    Fm*0.9 with live per-oscillator amplitude readout (CAP_ADJUST state, command,
    CapAdjustEvent, /cap_adjust endpoints, colour-graded UI in System settings)
    - tools/qcm_client.py + qcm_demo.py: Python control client wrapping the REST
    API with live WebSocket measurement streaming (requests, websocket-client)
    - OPC: drop SET nodes — setting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
2026-07-20 fix: remove unused gain settings and add stop button for lock failure in UI
2026-07-21 feat: implement mult_sel phase detector and 2^10 window in software
    Wire the qcm_rp_2026-07-21_1508 FPGA build's changes into the software.
    Phase detector (mult_sel):
    - Add per-oscillator phase_detect setter writing the new mult_sel_N register
    (1-bit: 0 = ATAN, 1 = multiplier), cached and re-applied on lock.
    - Thread SetPhaseDetectCommand through the api/worker command layers, expose
    POST /settings/phase_detect, persist it, and replay on boot.
    - Add a Phase Detection selector to the settings UI and a set_phase_detect
    client helper.
    Window size:
    - Shrink WINDOW_SIZE from 2^14 to 2^10 to match the FPGA scan window so the
    PLL start point lines up with the hardware sweep; update the lo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
2026-08-10 fix: report run-log failures instead of silently recording nothing
    A full SD card produced two 0-byte run CSVs on 2026-08-10. open() still
    created the file, the header flush hit ENOSPC, and RunLogger swallowed the
    error — so the run continued with logging disabled. Nothing in the UI showed
    it: the live plots come over the WebSocket and never touch the log file, and
    the only trace was a print in the journal. Both runs were unrecoverable.
    RunLogger now takes on_start/on_error callbacks, which the worker turns into
    RunLogStartedEvent / RunLogFailedEvent and pushes to the UI over the existing
    event path. Other changes:
    - Refuse to open a log below 100 MB free, warn below 500 MB (a run writes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
2026-08-10 feat: add reboot, target thickness, sweep logging and mode presets
    Reboot:
    - POST /system/reboot restarts the Pitaya, off the request thread so the
    response is delivered before the box goes down. Refused with 409 during a
    measurement unless forced, since a reboot ends that run where it stands.
    - Header button with a confirmation, then a modal that polls /health and
    reloads when the server answers again.
    Target thickness:
    - New setting under Measurement (0 = off). The worker compares each
    measurement and raises a flag on the first upward crossing: popup and
    header pill in the UI, a TARGET_REACHED row in the run CSV,
    GVL_QCM.READ.TargetReached on the PLC, and GET /measurement/targ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
2026-08-12 Refactor QCMWorker and related tools to remove auto amplitude thresholding
    - Removed auto amplitude thresholding logic from QCMWorker, including related configuration and event emissions.
    - Updated lock detection settings to use phase tolerance and phase standard deviation instead of amplitude threshold.
    - Enhanced telemetry reporting to include lock quality metrics (phase-error σ) during idle states.
    - Adjusted README and client interfaces to reflect changes in lock detection parameters.
    - Updated CSV plotter to visualize new quality metrics for mass and temperature locks.
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2026-09-03 feat: implement temperature hold and frequency tracking features
    - Added temperature hold functionality to maintain the last calculated temperature when the temp-mode lock is lost, preventing erroneous temperature readings.
    - Introduced frequency tracking to adjust the re-lock start frequencies based on the actual frequencies being held by the PLLs, improving lock recovery during long depositions.
    - Updated the settings panel to include options for enabling/disabling temperature hold and frequency tracking.
    - Enhanced the QCMWorker to handle new commands for temperature hold and frequency tracking settings.
    - Updated the QCMClient to support new API endpoints for managing temperature hold an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
2026-09-03 feat: let the temperature hold cover a temp-only lock loss
    A lost temp-mode lock with the hold on no longer counts as a lost lock for
    the automatic re-lock. Re-acquiring costs more there than it buys: there is
    one global reset register, so startupPLL re-parks both NCOs at pre-lock gain
    and blocks for up to ten attempts — seconds with no output, and the mass loop
    dragged through a re-acquisition it never needed — while the mass mode was
    measuring the film perfectly well throughout.
    Says so plainly in the TEMP_HOLD run-log event, the settings panel and the
    client docs: the measurement does not pause, only the thermal correction does.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
2026-09-03 feat: automatic gain control on the PLL drive
    The FPGA now scales each oscillator's excitation sinewave by output_gain_1 /
    output_gain_2 (Fixed 32.24, 1.0 = the unscaled drive the hardware had before
    the register existed). This drives that register from software.
    The AGC servos the gain so the demodulated amplitude holds at a target, which
    keeps the loop's SNR — and with it the phase noise the lock detect judges on —
    steady while the crystal's own response falls off with temperature and film
    loading. That drift is exactly what made an absolute amplitude threshold
    unusable as a lock test; holding the amplitude put back removes the cause
    rather than working around it.
    It only ever servos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
2026-09-22 docs: correct crystal cut from AT-cut to SC-cut
    The crystals in use are SC-cut, not AT-cut. Fix the misleading comments
    on the default calibration coefficients and the mass sensitivity, and
    the example profile name in the client README. The -13.3 ng/(cm2*Hz)
    mass sensitivity is Inficon's SC-cut figure; value unchanged.
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2026-10-19 docs: fold OFFLINE.md into the READMEs and restructure the main README
    OFFLINE.md mostly repeated tools/README.md and vendor/wheels/README.md.
    Its unique parts now live where a reader looks for them:
    - reinstalling the board offline and setting its clock: src/README.md
    - PC venv/pip details and the tkinter fallback: tools/README.md
    - reaching the instrument on the network: README.md
    The main README gains a repository layout table, a getting-started path
    and a short offline summary, and the algorithm section now says which
    coefficients are mass sensitivities. Code comments that pointed at
    OFFLINE.md now point at the right README or stand on their own.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
2026-10-19 fix: keep measuring through a lost lock, and re-lock only for the mass mode
    With the temperature hold off, a lost temp-mode lock fell through to the
    automatic re-lock, which calls startupPLL and returns before taking the
    sample. startupPLL is ten attempts of a one-second settle plus a window
    fill — some twelve seconds, spent in LOCKING with only telemetry going
    out — and it then resets the loss timer and fires again a second later.
    The run therefore produced about one second of measurements in every
    thirteen, which is why no temperature came out while unlocked even
    though FreqToTemp would have solved one perfectly well.
    Each attempt also pulses the one global reset and re-parks both NCO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
2026-10-19 fix: refuse to start when the bitstream fails to load
    load_bitstream reports every outcome as a dict, so `if not
    fpga.load_bitstream()` was false even for {"status": "error"} — a
    non-empty dict is truthy. The guard had therefore never fired: a failed
    load printed its reason and the server started regardless.
    That failure is near-invisible from the outside. The web interface comes
    up, and QCMInterface builds its register map from the newest .fpg file
    rather than from the hardware, so every write lands at a plausible
    address in whatever logic the FPGA happens to be holding. It reads as a
    broken instrument rather than a missing bitstream — which is exactly how
    it presented on a fresh Pitay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
2026-10-22 fix: commit the Simulink models with each bitstream build
    generate_and_push.sh committed only top.bit.bin and the .fpg, so every
    model change since 2026-05-28 reached the bitstream but never git: the
    .slx files in the repo fell months behind the hardware, and the newest
    design existed only in the build machine's working copy.
    The script now also stages changes to the tracked model_composer/*.slx.
    It warns when a model has unsaved Simulink changes, since only the saved
    version gets committed, and lists any untracked .slx rather than
    silently leaving it out.
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2026-10-23 fix(gui): load on Chromium/Edge older than v80
    An older lab PC failed to load the GUI with "SyntaxError: unexpected
    token '.'" at index.html:816. Its browser (Chromium 72-79) cannot parse
    optional chaining, and one such token rejects the whole inline script,
    leaving a dead page.
    - Replace every ?. and ?? with explicit checks or two small helpers,
    fieldValue(id) and ifNull(v, d); ifNull keeps a real 0 where || would
    not
    - Build chart options with a JSON deep copy instead of structuredClone
    (Chrome 98+), which would have broken every chart next
    - Spell out top/right/bottom/left instead of inset: 0 (Chrome 87+), so
    the modal backdrop covers the screen and the toggle switches render
    - N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
2026-10-23 perf(gui): redraw only the charts on the visible tab
    The GUI lagged on a slow PC. Every 100 ms the redraw timer updated all ten
    live charts, though only two to six are on the open tab: hidden ones still
    re-ran Chart.js's data and axis processing, which cost as much as drawing
    the visible charts.
    - Skip charts on a hidden tab in the redraw loop. They stay dirty and draw
    within one tick of their tab being opened, so nothing visible changes.
    - Fit the time-axis labels from a sample of 5 (ticks.sampleSize) instead
    of measuring all of them, up to 3000 on Main. The labels are all
    HH:MM:SS, so the ticks come out identical (checked on every live chart).
    Per redraw tick with full buffers, on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
2026-10-23 feat: status LEDs, non-blocking lock, uncompensated mode, OPC off by default
    Front-panel LEDs: the new bitstream wires the 4-bit led_control register
    to the GPIO, and domain/status_leds.py drives it. LED 1 is on once the
    bitstream is loaded and flashes at 2 Hz while a run has a problem (lost
    lock, a re-lock in progress, recording failed, no thickness); LEDs 2/3
    show the mass/temp lock (dark through sweeps, capacitor adjust and a
    parked mode); LED 4 is unassigned (set_aux). All go dark on shutdown.
    GET LOCK no longer blocks the worker. beginLock releases the loops and
    returns; the worker advances the attempt each acquisition cycle, so
    telemetry keeps streaming, and judges it once: success as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
2026-10-26 feat: unwrap the sweep phase on the Analysis tab and in sweep_plotter
    The demodulator reports the phase wrapped to ±π, so a trace passing ±π
    jumps by 2π and the shape across a resonance is lost in the jumps.
    Analysis tab: the phase trace is now unwrapped point by point as the
    sweep arrives (each step taken the short way round, a missing reading
    leaving a gap without breaking continuity), with the measured phase as
    a grey dashed line underneath. Lock points are still found on the
    measured phase, so the same points come out; their markers sit on the
    unwrapped trace, shifted by the whole turns added there. The lock-point
    line stays at ∓π/2, where the measured trace crosses it. The hove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
2026-10-26 fix(plotter): drop the raw-phase dashed line
    The grey dashed copy of the measured phase under the unwrapped trace
    adds nothing in the plotter. There is one phase trace again: unwrapped
    by default, the phase as measured when "Unwrap phase" is unticked, with
    the axis rescaled to whichever is shown. The web UI keeps its dashed
    line.
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2026-10-26 fix(temps): R22 sense resistor is 1 kΩ, not the assumed 2 kΩ
    The PT100 reads in direct proportion to it, so every PT100 reading
    would have been half the true resistance. Comments updated to match.
2026-10-28 feat(gui): adjustable TEMP SENSORS window; lowered windows now shrink
    - TEMP SENSORS tab: a WINDOW field (points per chart, default 3600 =
    one hour at the 1 s read interval), remembered per browser like the
    MAIN and MONITOR windows.
    - Fix: lowering any chart window had no effect. push() dropped at most
    one old point per new one, so a chart stayed at its old length for
    good. It now trims to the window in one go (trimToWindow), and a
    changed WINDOW field applies to every chart on its tab at once
    instead of waiting for the next point. Zoomed charts still keep
    everything until the zoom is reset, which trims through the same
    helper.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
2026-10-28 fix(temps): cold junction no longer flagged "under range" at room temperature
    The LTC2986 only vouches for active-analog readings from the second row
    of the sensor's table up: anything below it is a "sensor under range"
    soft fault, which the thermocouple then reports as a cold-junction soft
    fault. The first row is just the anchor it extrapolates down to
    (datasheet Table 68, Figure 54).
    The TSic 501F table started at (0 mV, -10 °C), (500 mV, 25 °C), so
    every reading below 25 °C was flagged. It is now (-1000 mV, -80 °C),
    (0 mV, -10 °C), (1000 mV, 60 °C): the anchor sits on the same line below
    the sensor's range, and the flagged range is the TSic's real
    -10..+60 °C. Temperatures are unc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
2026-10-28 feat(lock): lock on the stored start frequencies when the service starts
    - The server queues the same lock GET LOCK sends straight after the boot
    settings push, with the active crystal's start frequencies. Queued
    behind the measurement mode, so uncompensated still locks the mass mode
    alone and a 0 Hz start frequency still parks its oscillator.
    - Fix: a fresh start overwrote the start frequencies with 0 Hz. The boot
    push turns the integrators on with the NCOs at 0 Hz, their phase passes
    the lock test, and frequency tracking (running in IDLE) followed it. A
    sweep or capacitor adjustment did the same with the loops left open.
    The worker now only lets tracking and the end-of-run up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
2026-10-28 feat(calibrate): settle detector on the Pitaya; LTC2986 readings in the run log
    Run log:
    - Every row carries the newest LTC2986 readings: pt100_c, thermocouple_c,
    cold_junction_c (degC) and temp_sensor_faults. Blank without a current
    reading; a failure there blanks those columns only, never the row.
    - The temperature worker keeps its latest event for the QCM worker's logger.
    - csv_plotter can plot the three sensor columns.
    Calibration points (domain/calibration_recorder.py):
    - Points are taken and stored on the Pitaya (data/calibration/points.json,
    gitignored) instead of in the browser, so they survive a reload/restart.
    - A settle detector judges each window: both modes locked, fT dri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
2026-10-28 fix(calibrate): no automatic point while the crystal is leaving a plateau
    On the Pitaya a second point was taken 1:44 after the first, 5 Hz off the
    old plateau: fT jumped ~100 Hz in the last few seconds when the Peltier was
    turned down. The three-minute drift fit hardly registered it, so the state
    stayed "settled", while the re-arm check looked only at the newest second,
    which already counted as a new temperature. In simulation the same jump
    gave a burst of points.
    - fT has left the last point only once it stays more than REARM_HZ away
    for DEPART_S (10 s) in a row; from then on the window reaches back no
    further than that, so the next point is judged and averaged on the new
    temperatur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
2026-10-28 feat(gui): crystal electrode symbol as tab icon and header logo
    - favicon.svg: the electrode side of the sensor crystal, gold on dark
    quartz - centre electrode, gap ring bridged at 3 and 9 o'clock, outer
    ring slotted at 12 and 6. Slots and bar sit on whole pixels at 16 and
    32 px so they stay legible as a tab icon.
    - favicon.ico (16/32/48 px PNGs rendered from the SVG) for the lab PC's
    Chromium 72-79, which predates SVG favicons; it skips the SVG link by
    its type. Newer browsers take the SVG.
    - The header logo next to QCM MONITOR is now the same favicon.svg.
    - The server nails .svg to image/svg+xml: SVG is never sniffed, so any
    other type leaves the icon blank.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
2026-11-02 feat(temps): Zynq die temperature in the run log and TEMP SENSORS tab
    Over the 30 Oct - 2 Nov weekend every load change on the Pitaya shifted
    both modes by the same fraction, ~0.3 ppm per degC of board temperature:
    the reference clock, which the dual-mode compensation reads as mass. The
    TSic on the V2 board is only a proxy for the oscillator; the Zynq's own
    die sensor sits on the same board as it, so log that too and see which
    tracks the error better.
    - domain/zynq_temperature.py reads the XADC through IIO (name "xadc",
    in_temp0_raw/offset/scale) and averages 128 conversions: ~45 ms and
    +-0.025 degC on the Pitaya (one count is 0.12 degC).
    - The temperature worker reads it every round, i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
2026-11-03 feat(measurement): take T start from the crystal itself
    The calibration fit gives both modes' whole curves, constants included, so
    the two frequencies say the crystal's temperature without a thermometer and
    without its lag: Settings -> Measurement -> T Start Source -> Crystal.
    - processing.TempCompAlgorithm.absolute_temperature solves it from
    fT - rho*fM with rho = fT_0/fM_0. Deposited film and reference-clock
    errors cancel in that combination; a shift of one mode alone does not
    (1 Hz on fM is about 0.01 degC).
    - The QCM worker solves it as the run starts, only with both modes locked
    and on resonance in the newest sample: the 10:32:45 try on 3 Nov anchored
    on a temp mode still pul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
2026-11-04 fix(temps): one Zynq die conversion a second, averaged over the last minute
    The 128 back-to-back XADC conversions per read took ~56 ms, and every
    frequency sample taken during them dipped by up to 30 mHz (4 ppb) in both
    modes: 13-17 spikes a minute, fT noise 9 mHz instead of 6. A single
    conversion takes 0.6 ms and is indistinguishable from no read at all
    (3 Nov 2026 variant test). It resolves only 0.12 C, but scatters enough to
    dither, so the mean of the last 60 is good to ~0.02 C.
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2026-11-10 feat(acquisition): settable sample rate, 100 Hz by default, apart from display and log rates
    The worker now samples on a fixed schedule at Settings -> Measurement ->
    Sample Rate (1-100 Hz, default 100) instead of a 100 ms queue timeout plus
    the cycle's work (9.04 Hz measured). Every sample feeds the deposition rate,
    the target check and the lock automation. The GUI and PLC (Display / PLC
    Rate, 1-25 Hz, default 10) and the run log (Log Rate, default 10 Hz,
    0 = every sample) each take the newest sample on their own schedule
    (domain/acquisition.py), so a reactive short-window rate no longer floods the
    browsers, the PLC or the SD card. POST /settings/acquisition; the SETTINGS
    row records all thr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
2026-11-13 feat(calibration): automatic calibration sequence on the TEC
    The Pitaya now works through a list of TEC setpoints by itself
    (domain/calibration_sequence.py, ticked by the server right after the settle
    detector). A point step goes to its setpoint and waits for the detector's
    automatic point there; a soak holds its setpoint for some minutes and,
    optionally, until the mass mode drifts less than a limit (break-in, anneal).
    - Settings -> Calibration Sequence: a generator (range, step, interleaved /
    both ways / up only, break-in, anneal, reference points before and after
    the anneal and at the end), an editable step list with a rough duration,
    step timeout and what to do on it (skip / take a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
2026-11-13 feat(calibration): one hot soak for break-in and anneal in the sequence generator
    Heat speeds up a fresh crystal's break-in, so the generator now puts a single
    soak before the points: at the anneal temperature, for at least its minutes
    and until the mass mode drifts less than the limit (defaults 52 degC, 60 min,
    0.02 Hz/min). It replaces the separate break-in at the reference and anneal
    soaks, and drops the reference point that came between them, which a fresh
    crystal would have given mid-break-in. Defaults now give 12 steps with 11
    points over 10-50 degC. Saved sequences keep their steps; only the generator
    inputs changed.
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
